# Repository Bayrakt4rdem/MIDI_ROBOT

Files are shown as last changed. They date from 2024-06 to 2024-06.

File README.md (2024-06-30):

# MIDI ROBOT

###### *Built for:*
- METU ME Department ME462 Capstone Project
###### *Built by:*
- Ege Sarp Dengizmen
- Erdem Bayraktar
- Muhammed Ömer Yiğit
- Omar Habib
- Seçkin Eren Yetim

<p align="center">

</p>

## Showcase Video
MIDI ROBOT SHOWCASE (https://www.youtube.com/watch?v=wqPkPyw_Kpk)

## Motivation of the Project

### What is MIDI Robot?
MIDI is a robotic project that focuses on improvised programmability and easy integration of additional sensors. It is made to be long-lasting and versatile with a design that conveniences assembly and manufacturing processes.

Its modular design is key to its ease of integration of new sensors and tools as mission needs change. This flexibility increases the robot's capacity to carry out a wide range of scientific studies for indoor environments with uninterruptable power supply.

Essential component of MIDI is its programmability, which gives researchers the ability to alter and improve robotic operations in real time with built in sensors and expandability. With comprehensive array of sensors and convenience to control them, it can be utilized by wide range of users that includes anyone from a beginner to a PhD student.

### Why is MIDI Robot Necessary?
Understanding the basic of robotics requires wide range of information from diverse professions combined. In fact, learning all discreate subject is exhausting and discouraging. MIDI robot is specifically designed to programming in ease by user. Furthermore, building and assembling this robot may teach the user diverse information about power electronics, mechanics and programming that includes pi pico and python with considerably less effort.

For expert users, MIDI may be considered as a strong candidate for testing their algorithms, making scientific researches or just for fun. With the expandable sensor design with proper communication between them, one can implement diverse tasks to MIDI without any worries about power-loss issues or lose data.

### Motivation Behind the Project
Learning the theoretical part of the robotic is always enjoyable for us. Still, without proper application, this knowledge is likely to be forgotten or become meaningless. For this project, we have aimed to apply our theoretical skills to build a robot that makes us feel satisfied. Still, building the robot was challenging. We learned lots of things while solving the problems that we faced. In fact, one can say that theory feeds the application but applicational issues creates the theory.

The main idea behind building the MIDI is helping the people to make their own robots to learn more about robotics and testing their codes and theoretical implementations. All the code implementations and mechanical designs are specifically made for learning the robotics in more convenient way. In fact, From high-school student to graduate students, anyone that really interested in robotics can use this robot to make some additions, to make some experiments or daily use that includes lots of fun.

### Acknowledgement and Credits

While doing this robot, we have faced diverse problems that is about the facility problems and guiding.   
We would like to thank the Ahmet Buğra Koku for guiding us, ROMER and METU Micromanufacturing Laboratory for allowing us to use their manufacturing infrastructure and resources.

## Main features

Structrually MIDI is expected to carry 15 kilograms without facing any problems. It is specifically designed for indoor use. Still, one can change some of the mechanical components of the MIDI to adapt MIDI for outdoor use.

With its modular design, one can add different sensors and payloads to the platform. Due to its modular design, it is very easy to add extra floors to the MIDI.

There are 4 bumpers on the corners of the robot to sense the collision of MIDI. These bumpers both act as a sensor and a mechanical spring.

4 ultrasonic sensors are implemented to sense the distance of the robot with respect to outer obstacles. This sensors can be used to prevent crashes and fall downs. 

A lidar, a wide-angle camera and an IMU is also implemented to perceive the environment in an enhanced manner to achieve diverse tasks.

As a power source an 18V Makita battery is used. There is also an extra UPS module on the robot, in order to prevent direct power cuts of the Raspberry Pi. 

## Shared Documentation and Files

  1. Bill of materials to make replication of the device easier
  2. PCB circuitry design and electronic schematic files   
  1. CAD design files to make further development available   
  1. STL design files for 3D printing availability
  1. Assembly manual for an easier assembly
  2. Software explanations and guides
  3. Example use cases

## Bill of Materials

### Off-the-shelf Materials Which Must be Purchased

To build the model that provided, one will need diverse sensors and components. One can found the necessary materials with some sample links below. 

#### Electronic components
- [MPU6050 IMU x 1](https://www.robotistan.com/mpu6050-6-eksen-ivme-ve-gyro-sensoru-6-dof-3-axis-accelerometer-and-gyros)
- [YL99 Impact Switch Module x 4](https://www.robolinkmarket.com/yl-99-darbe-svic-sensor-modulu)  
- [HC-SR04 Ultrasonic Distance Sensor x 4](https://www.robotistan.com/hc-sr04-ultrasonic-distance-sensor)
- [A4988 Stepper Motor Driver x2](https://www.robotistan.com/a4988-step-motor-surucu-karti-kirmizi)
- [YDLidar G2 x1](https://www.robotistan.com/ydlidar-g2-lidar-mesafe-sensoru)
- [NEMA17 Stepper Motor x 2](https://www.robolinkmarket.com/17hs4401-nema17-step-motor) 
- [Makita 18V Battery x1](https://www.powertoolworld.co.uk/brands/makita/makita-batteries-chargers/makita-batteries-18v-lxt)
- [UPS Module 3S x 1](https://www.amazon.com.tr/waveshare-Kesintisiz-UPS-Destekler-3S/dp/B0BQC2WNR8)
- [Rasberry Pi Pico x 1](https://www.robotistan.com/raspberry-pi-pico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)
- [Rasbeery Pi 4 x 1](https://www.robotistan.com/raspberry-pi-4-4gb)
- [lm2096 Voltage Regulator x 2](https://www.robotistan.com/mini-ayarlanabilir-3a-voltaj-regulator-karti-lm2596-adj) 
- [XL4016E1 DC-DC Step Down x 1](https://www.az-delivery.de/en/products/xl4016e-yh11060d)
- [Megapixel Wide Angle Fish Eye Camera x 1](https://www.amazon.com/Hilitand-Fisheye-Professional-Adjustable-Raspberry/dp/B0877439FF)
- [30x30 Fan x 1](https://www.rhino3dprinter.com/urun/30x30-fan-12v-ve-24v-secenekleriyle)
- [8 Strip Led x 2](https://www.robolinkmarket.com/neopixel-8li-serit)
- [100 μf Capacitor x 1 ](https://www.robotistan.com/25v-100uf-capacitor)
- [10 μf Capacitor x 2 ](https://www.robotistan.com/10-uf-16-v-elektrolit-kondansator)
- [20 pieces Neopixel Led strip x1](https://market.samm.com/adafruit-neopixel-dijital-rgb-led-serit-siyah-60-led-1m)

  Note that other NEMA17 models or other power supply models may be selected. Still, battery must be adjusted as 18 Volts.

#### Structural components

- [20x20 Sigma Profile 30cm x4](https://www.robolinkmarket.com/20x20-v-slot-sigma-profil-kanal-6-320mm)   
- [20x20 Sigma Profile 21cm x4](https://www.robolinkmarket.com/20x20-v-slot-sigma-profil-kanal-6-320mm)   
- [20x20 Sigma Profile 15cm x4](https://www.robolinkmarket.com/20x20-v-slot-sigma-profil-kanal-6-320mm)   
- [Sigma Connection Component x 12](https://www.robolinkmarket.com/20x20-genis-kose-baglanti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)   
- [M3 16mm Screw x 30](https://www.amazon.com/Phillips-Countersunk-Machine-Screws-100pcs/dp/B018RSUVFU)   
- [M4 16mm Screw x 30](https://www.amazon.com/Phillips-Machine-Screws-Metric-Thread/dp/B01HF7BLIA)   
- [M3 Nuts x 30](https://www.robotistan.com/m3-somun-50-adet)   
- [M4 Nuts x 30](https://www.robotistan.com/m4-somun)
- Bearings in specified dimensions in assembly step file.

  Note that sigma profiles are sold as whole 4-6 meters. Buying one and cutting in proper dimensions is necessary.

### Printed Parts
To make the MIDI robot more accessible and easy to replicate, most of the parts are suitable for 3D printing.    
The production files can be found under the /CAD_files directory.   
The STEP files are for further development and editing the model in any CAD environment. <br>
The STL files are for manufacturing the necessary parts with a 3D printer. <br>
 <br>
 
Note that soldering equipment will also be needed.
Below is the list of all the printed parts: 

1. Led casing part 1 x2 // CAD file name: Led_casing_part1
1. Led casing part 2 x2 // CAD file name: Led_casing_part2
1. Makita holder x1 // CAD file name: Makita_holder
1. Raspbery Pi holder bottom part x1 // CAD file name: Rasp_pi_holder_bottom
1. Raspberry Pi holder top part x1 // CAD file name: Rasp_pi_holder_top
1. UPS holder x1 // CAD file name: UPSholder
1. Ultrasonic sensor holders x4 // CAD file name: Ultrasonic_holder
1. Bumper x4 // CAD file name: bumper
1. Button box x1 // CAD file name: button_holder
1. Camera holder x1 // CAD file name: camera_holder
1. Rim caster tire x4 // CAD file name: castertire_rim_v1
1. Alternative for caster tire x4 // CAD file name: castertire_v1
1. Alternative for caster tire x4 // CAD file name: castertire_v2
1. Alternative for caster tire x4 // CAD file name: castertire_v3
1. Alternative for caster tire x4 // CAD file name: castertire_v4
1. Alternative for caster tire x4 // CAD file name: castertire_v5
1. Main PCB holder x1 // CAD file name: mainPCBholder
1. Main tire alternative rim x2 // CAD file name: maintire_rim_v1
1. Main tire alternative rim x2 // CAD file name: maintire_rim_v2
1. Main tire alternative x2 // CAD file name: maintire_v1
1. Main tire alternative x2 // CAD file name: maintire_v2
1. Sigma sensor and modular holder connection x16 // CAD file name: modular_sigma_connections
1. Plexy holders x8 // CAD file name: plexy_holder
1. Power PCB  holder x1 // CAD file name: powerPCBholder
1. Sigma corner connection x8 // CAD file name: sigma_corner_connection
1. Alternative sigma corner connection x8// CAD file name: sigma_corner_connection_previous
1. Spring version 1 x4 // CAD file name: spring_v1
1. Spring version 2 x4 // CAD file name: spring_v2
1. Wheel holder part x3 // CAD file name: tire_holder
1. Side wheel gear 1 // CAD file name: wheel_holder_gear1
1. Side wheel gear 2 // CAD file name: wheel_holder_gear2
1. Side wheel carrying assembly part 1 x2 // CAD file name: Wheel_holder_part1
1. Side wheel carrying assembly part 2 x2 // CAD file name: wheel_holder_part2
1. Back wheel carrying assembly x1 // CAD file name: Back_wheel_holder
1. Caster tire holder x4 // CAD file name: Caster_tire_connectors

## Printing Settings for 3D Printed Parts

There are 2 main materials and settings used for 3D printed parts.   
For the elastic components such as springs and tires, TPU material is used.   
For the remaining parts, PLA material is used.   

[Link for the TPU filament](https://www.porima3d.com/porima-tpu-flex-esnek-95a-filament-175mm-1kg)   
[Link for the PLA filament](https://www.porima3d.com/porima-pla-filament-175mm-1kg)     

The production files can be found under the /CAD_files directory.   
The STEP files are for further development and editing the model in any CAD environment. <br>
The STL files are for manufacturing the necessary parts with a 3D printer. <br>
 <br>
 
The recommended settings for slicing the STL files for PLA material are as follows: <br>
3D Printer Model: Creality CR-6 SE 
Material: PLA filament <br>
Nozzle / build plate temperature: 210 / 65 degrees <br>
Layer height: 0.2 mm <br>
Initial layer height: 0.2 mm <br>
Line width: 0.4 mm <br>
Wall line count: 3 <br>
Infill density: 30.0% <br>
Infill pattern: Lines <br>
Print speed: 70.0 mm/s <br>
Infill speed: 100.0 mm/s <br>
Wall speed: 35.0 mm/s <br>
Initial layer speed: 35.0 mm/s <br>
Fan: ON <br>
Supports: ON / Normal 45 degree overhang <br>
Adhesion type: NO <br>

The recommended settings for slicing the STL files for TPU material are as follows: <br>
3D Printer Model: Ender 3 V2 (modified for direct drive extrusion)
Material: TPU filament <br>
Nozzle / build plate temperature: 215 / 65 degrees <br>
Layer height: 0.2 mm <br>
Initial layer height: 0.2 mm <br>
Line width: 0.8 mm <br>
Wall line count: 3 <br>
Infill density: 100.0% <br>
Infill pattern: Lines <br>
Print speed: 50.0 mm/s <br>
Infill speed: 50.0 mm/s <br>
Wall speed: 25.0 mm/s <br>
Initial layer speed: 35.0 mm/s <br>
Fan: ON <br>
Supports: OFF / Normal 45 degree overhang <br>
Adhesion type: NO <br>

## Power Circuitry

Basically in our power circuitry we have 18V, 12.8V, 5V, 3.3V power lines.

- 18 Volts Power is used to feed UPS and the UPS feeds the Raspberry Pi
- 18 Volts power is transformed into 12 Volts to feed the steppers
- 12 Volts power is transformed into 5 Volts to feed the led strips
- 12 Volts Power is also transformed into 3.3 Volts to feed the Raspberry Pi Pico and rest of the sensors.

### Electronic Diagrams & PCB Designs

The PCB Files and Electronic Schematics can be found under the PCB&Schematics/ directory.  
The Fusion 360 software is used while designing the PCB circuit. <br>

The PCB is designed as single layer, in order to make fabrication process easier. <br>
But due to size limitations of the PCB, not all the wiring fit into one layer. <br>
As a result there is two options: <br>
Easier option: Fabricate only the top layer as a single layer PCB and make additional air wiring afterwards.<br>
(less than 10 additional airwires are  necessary). <br>
Second option: Fabricate the PCB as a two layer one. <br>

### Assembly Guideline

1. Cut the sigma aluminum profiles in given lenghts.
1. Insert the sigma modular holders into specific positions on sigma slots, as you wish.
1. Insert the led casings into the two sides of the sigmas.
1. Connect the sigma aluminums using sigma corner connections and obtain a rectangular sigma box.
1. Assemble the side wheel holder assembly, insert gearbox inside and mount the stepper motors.
1. Connect the side wheel assembly to the main sigma body using wheel holder part.
1. Connect the back wheel carrying assembly to the main sigma body using wheel holder part.
1. Insert the caster tire holders and connect the caster tires into them.
1. Connect the main wheels.
1. Insert the springs on above wheels.
1. Mount the plexy plates on both floors.
1. Insert sensors and components using their own casings and holders.
1. Make the necessary cablings and check the circuit using a multimeter.
1. Now you can power up your robot and start HAVING FUN!

## Software Documentation

### Software and Versions
### Installing Guide
This project uses a Raspberry Pi 4b as the main computer of the robot. Flash the latest Raspberry Pi OS 64-bit version onto your sd card. We recommend using the **PiImager**. Make sure to configure your image to your needs (enable SSH, set wlan key and password, setup username and password). Flash the sd card, insert it into your Pi and power it on. Now, to **SSH** into RPi4, open up a terminal on the PC and use the command `ssh pi@<yourusername>.local`. The console will ask for your password, enter it. In order to setup the Pi, you should clone the software files repo into your home adress using `git clone`, after the files are cloned go inside the `Raspi_files`. Inside the `Raspi_Files` folder give execution rights to the setup file using, `chmod +x setup_pi.bash` and then relax :) the script will take care of all the Pi configuration, docker installation, building of the docker container, adding necessesary configs modifications etc. Feel free to inspect the bash script. <br>
**Important Note:** this script adds a function to your `.bashrc` such that everytime you ssh into your Pi the project docker container opens up. You can modify your `.bashrc` file to change this behaviour as needed.  <br>
After the script the Pi will reset itself, you can just go inside `Examples` and try some examples. Provided that you pip installed the projects python package. See below for that. <br>
### Why Use Docker?
We have opted with using a Docker image because it allows for end-users like you to get right into the action with a ready to use image with all required dependencies of our project pre built into it. One more advantage of this is even if you are not running on a RPi 4 you can still use the Dockerfile provided in **Docker_files** folder to build the ready to use image and get started on whatever software you are running. If you want to add functionality just modify the docker file and rebuild it again.
<br>

### Rasberry Pi Pico/ESP
MIDI has Raspberry Pi Pico W microcontroller. MIDI can be used with any microcontroller(ESP32) that can be coded in MicroPython. <br>
To flash MicroPython into Pico W, this [tutorial](https://projects.raspberrypi.org/en/projects/getting-started-with-the-pico/3) could be followed. After flashing MicroPython, the provided scripts should be uploded into Pico W from [here](https://github.com/momeryigit/ME462-MIDI/tree/omar-test/sarp-esp).

#### Pico Side Command Handler

This document explains the different commands handled by the `command_handler` function on the Pico microcontroller. Each command is parsed and executed to control various components like stepper motors, Neopixel LEDs, and other functionalities.

##### Command Format

Commands are received as a list (`msg`) where:
- `msg[0]`: Command identifier (e.g., `"s"`, `"t"`, `"np"`, `"h"`, `"PAUSE"`, `"CONTINUE"`, `"EMERGENCY_STOP"`, `"re-config"`).

#### Supported Commands:

##### Stepper Motor Commands

1. **Drive Stepper at a Frequency**
    - Command: `"s l 500"`
    - Description: Drives the specified stepper at a given frequency.
    - `msg[1]`: Stepper identifier (`"l"` for left, `"r"` for right).
    - `msg[2]`: Frequency in Hz.
    - Example: `"s l 500"` drives the left stepper at 500 Hz.

2. **Drive Stepper for a Number of Ticks in a Duration**
    - Command: `"t r 100 5"`
    - Description: Drives the specified stepper for a certain number of ticks within a given duration.
    - `msg[1]`: Stepper identifier (`"l"` for left, `"r"` for right).
    - `msg[2]`: Number of ticks.
    - `msg[3]`: Duration in seconds.
    - Example: `"t r 100 5"` drives the right stepper 100 ticks in 5 seconds.

###### Neopixel LED Commands

1. **Turn Off All Neopixels**
    - Command: `"np off"`
    - Description: Turns off all Neopixel LEDs.

2. **Fill All Neopixels with a Color**
    - Command: `"np fill 100 0 0"`
    - Description: Fills all Neopixels with the specified RGB color.
    - `msg[2]`: Red value (0-255).
    - `msg[3]`: Green value (0-255).
    - `msg[4]`: Blue value (0-255).
    - Example: `"np fill 100 0 0"` sets all Neopixels to red.

3. **Set Specific Neopixel Color**
    - Command: `"np set 1 4 0 55 0"`
    - Description: Sets a specific Neopixel's color.
    - `msg[2]`: Neopixel strip ID.
    - `msg[3]`: Pixel index in the strip.
    - `msg[4]`: Red value (0-255).
    - `msg[5]`: Green value (0-255).
    - `msg[6]`: Blue value (0-255).
    - Example: `"np set 1 4 0 55 0"` sets the 4th pixel of strip 1 to green.

###### Control Commands

1. **Heartbeat Response**
    - Command: `"h"`
    - Description: Resets the watchdog timer to keep the system alive.

2. **Pause Operation**
    - Command: `"PAUSE"`
    - Description: Pauses all operations until the `CONTINUE` command is received.

3. **Continue Operation**
    - Command: `"CONTINUE"`
    - Description: Resumes operations after a `PAUSE`.

4. **Emergency Stop**
    - Command: `"EMERGENCY_STOP"`
    - Description: Immediately stops all stepper motors and sets Neopixels to a warning color.

5. **Re-configure Robot**
    - Command: `"re-config"`
    - Description: Re-initializes the robot, waiting for a handshake and a new configuration file.
    - Note: Must send the `PAUSE` command before re-configuring.

##### Usage Example

Here is an example of how the `command_handler` might be used in a script:

```python
# Example usage of command_handler
msg = ["s", "l", "500"]

msg = ["np", "fill", "100", "0", "0"]

msg = ["PAUSE"]

msg = ["CONTINUE"]
```

##### Function Parameters

- `comm`: An instance of the `SerialComm` class for communication.
- `msg`: List containing the parsed command message.
- `hb`: An instance of the `Heartbeat` class.
- `steppers`: An instance of the `Steppers` class.
- `sensors`: An instance of the `Sensors` class.
- `neopixels`: An instance of the `NeoPixelStrips` class.

### Notes

- Ensure the `PAUSE` command is sent before the `re-config` command to safely re-initialize the robot.
- The `GET_STATUS` commands is a placeholder and will be implemented soon.
- Test the pico commands directly, for example, by using [Thonny](https://thonny.org/).

### API
Midibot's API is open-source and published on PYPI (see the latest version [here](https://pypi.org/project/romer-midibot/)). It requires Python 3.6 or newer and `pyserial`.

To install `pyserial`, you can use:
```bash
pip install pyserial
```

To install `romer-midibot`, you can use:
```bash
pip install romer-midibot
```

This API is designed to connect to, control, and get readings from Midibot using Python. First, import the `DifferentialDriveRobot` class:
```python
from romer_midibot import DifferentialDriveRobot as Robot
```

To initialize a robot class:
```python
robot = Robot(serial_port="replace_with_your_serial_port")
```

#### The arguments are as follows:
- **`serial_port` (str)**: Serial port on PC or Raspberry Pi for connecting to the robot.
- **`baudrate` (int, optional)**: Baud rate for serial communication. Defaults to 115200.
- **`timeout` (int, optional)**: Timeout in seconds for communication operations. Defaults to 1.
- **`ip` (str, optional)**: IP address of Pico for socket communication. Defaults to "192.168.137.28".
- **`config_file` (str, optional)**: Path to the config.json file. Defaults to None.
- **`socket_port` (int, optional)**: Port for socket communication on PC or Raspberry Pi. Defaults to 8080.
- **`stepper_ids` ([int], optional)**: Integer array of stepper motor IDs. Defaults to [1, 2].
- **`u_ids` ([int], optional)**: Integer array of ultrasonic sensors. Defaults to [1, 2, 3, 4].
- **`b_ids` ([int], optional)**: Integer array of bumper sensors. Defaults to [1, 2, 3, 4].
- **`imu_connected` (bool, optional)**: Whether IMU is connected. Defaults to False.
- **`u_median_filter_len` (int, optional)**: Length of median filter window. Defaults to 3.
- **`default_emergency_behavior` (bool, optional)**: Default behavior of bumper switches coded on Pico. Defaults to True. Change to False if custom behavior is desired. Bumper switches will be polled for data if enabled.

To initialize the robot API, there are two methods:
1. Manually enter parameters into the class initializer.
2. Use a config file.

* **1**: To initialize by manually entering parameters, keep `config_file` as `None` and modify the other default parameters as desired. The API enables/disables robot peripherals as defined by initialized parameters from the user, which will be merged with a default [config_file](https://github.com/momeryigit/ME462-MIDI/blob/main/romer_midibot/romer_midibot/default_configs.py) to send to the Pi Pico.

* **2**: To use a config file, ignore the other parameters, and provide the path to your `config_file.json`. It should be similar to [this](https://github.com/momeryigit/ME462-MIDI/blob/main/romer_midibot/romer_midibot/default_config.json). Example:
```python
robot = Robot(serial_port="COM6", config_file=r"path/to/your/config/file")
```

Once your robot is initialized, you can connect via serial or socket (still in development) as follows:
```python
robot.connect(connection_type="serial")
```
```python
robot.connect(connection_type="socket")
```
Given that the Pi Pico is running and waiting for a connection, handshakes will be exchanged, and the config file will be sent to the Pico where it will initialize from it. If all this is successful, you are ready to send commands to the robot and receive data from it. The API will start a thread just to poll serial or socket ports and manage received data.

#### Robot Commands
* To set a data callback function that will be called whenever data is received:
```python
robot.set_data_callback(callback)
```
  - **`callback`**: Callback function called with raw data, whenever received from serial. Keep it low cost to prevent lag in data polling.

* To manually send a command to the robot:
```python
robot.send_command(command)
```
  - **`command`**: Command string sent to Pico.

* To send a pause command:
```python
robot.send_pause_command()
```
This stops all the robot's movements and data sending until either a continue or re-config command is received.

* To send a continue command:
```python
robot.send_continue_command()
```

* To disconnect from the robot:
```python
robot.disconnect()
```

* To configure the Pico with the sensor and motor configuration:
```python
robot.pico_config()
```

* To reconfigure the Pico with a new configuration file:
```python
robot.pico_reconfig(config_file)
```
  - **`config_file`**: Path to the new configuration file.

* To set the number of ticks and duration for the left and right wheels of the robot:
```python
robot.set_ticks_duration(left_ticks, right_ticks, duration_l, duration_r)
```
  - **`left_ticks`**: Number of ticks for the left wheel.
  - **`right_ticks`**: Number of ticks for the right wheel.
  - **`duration_l`**: Duration for the left wheel to complete the ticks. In s
  - **`duration_r`**: Duration for the right wheel to complete the ticks. In m

* To set the distance for each wheel and the duration to reach the distance:
```python
robot.set_distance_duration(left_distance, right_distance, duration_l, duration_r)
```
  - **`left_distance`**: Distance for the left wheel. In m
  - **`right_distance`**: Distance for the right wheel. In m
  - **`duration_l`**: Duration for the left wheel to reach the distance. In s
  - **`duration_r`**: Duration for the right wheel to reach the distance. In s

* To set the speed of the left and right wheels of the robot:
```python
robot.set_speed(left_speed, right_speed)
```
  - **`left_speed`**: Speed, in frequency, of the left wheel.
  - **`right_speed`**: Speed, in frequency, of the right wheel.

* To move the robot forward for a specified duration:
```python
robot.move_forward(duration=1, speed=500)
```
  - **`duration`**: Duration, in seconds, to move forward. 
  - **`speed`**: Speed, frequency, at which to move forward.

* To rotate the robot at a given speed in a given direction for a set duration:
```python
robot.rotate(duration=5, speed=800, direction="cw")
```
  - **`duration`**: Duration to rotate. In seconds
  - **`speed`**: Speed at which to rotate. In frequency
  - **`direction`**: Direction to rotate ("cw" for clockwise, "ccw" for counterclockwise).

* To convert desired linear and angular speeds to wheel frequencies and set the robot speed:
```python
robot.send_twist(linear_speed, angular_speed)
```
  - **`linear_speed`**: Linear speed. In m/s
  - **`angular_speed`**: Angular speed. In rad/s

* To stop the robot:
```python
robot.stop()
```

* To immediately stop the robot:
```python
robot.emergency_stop()
```

* To turn off the LEDs on the robot:
```python
robot.turn_leds_off()
```

* To fill all LEDs with a given color:
```python
robot.fill_leds(color)
```
  - **`color`**: Color to fill the LEDs with. RGB tuple (100, 20, 20) for example

* To set the color of a single LED pixel:
```python
robot.set_led_pixel(np_id, pixel_index, color)
```
  - **`np_id`**: ID of the neopixel strip.
  - **`pixel_index`**: Index of the LED pixel.
  - **`color`**: Color to set the LED pixel. RGB tuple (100, 20, 20) for example

* To get sensor data from the robot (default is ultrasound sensor data):
```python
robot.get_sensor_data(sensor_type="u")
```
  - **`sensor_type`**: Type of sensor data to get ("u": ultrasonic, "b": bumper, "i", imu).

* To request the current status of the robot:
```python
robot.get_status()
```

* Destructor to stop the robot and disconnect on deletion:
```python
del robot
```

Be sure to send disconnect command before unplugging the pico. Refer to examples or demos for example uses of the API.

## Trying out the ROS nodes
Midibot comes with some essentials to get you starting on using ROS2 on midibot. The provided docker container is ROS2 ready, all you have to do is go inside the `dev_ws` folder and run `colcon build --symlink-install`. This will build the source files and ready up your systen for testing. After build is complete make sure to source the enviorement by using `source install/setup.bash` (.bash/.zsh depending on the terminal you are using). This command essentially includes our ROS2 packages in that current terminal session. The core ROS installation is sourced in every terminal since `source /opt/ros/iron/setup.bash` is included inside the .bashrc file of the docker image. The command simply overlays our package contents over the core ROS2 installation. <br>
After sourcing you can get into testing. Simply run the launch file for RPi using `ros2 launch midi_bringup pi.launch.py`, this runs the node for serial communication and the lidar if given as an argument `ros2 launch your_package pi.launch.py lidar:=true`. Then on your PC again source the ROS2 enviorement and run `ros2 launch midi_bringup drive.launch.py`. This sets up the PC side nodes, opens Rviz and sets up the controller nodes. Then by connecting an xbox controller to your machine you can control the robot using the controller. <br>

## Conclusion
The MIDI Robot is a versatile and accessible platform designed for both beginners and experts in robotics. Its modular design and easy programmability allow users to integrate new sensors and tools as needed, making it adaptable for various scientific and educational applications. With MIDI, users can gain hands-on experience in electronics, mechanics, and programming, bridging the gap between theory and practice. This robot is ideal for learning and experimenting, providing an approachable entry point for newcomers while offering advanced capabilities for seasoned researchers. Overall, the MIDI Robot empowers users to explore and innovate in robotics, making it a valuable tool for education, research, and personal projects. Its design ensures reliability and ease of use, fostering a deeper understanding and appreciation of robotic systems.

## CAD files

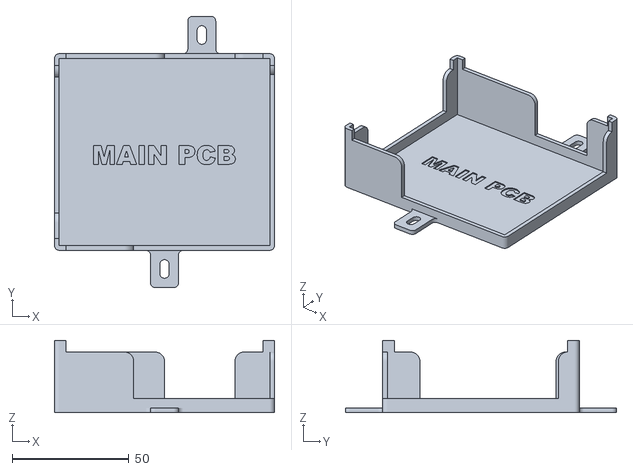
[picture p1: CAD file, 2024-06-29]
CAD_files/STL_files_to_3Dprint/mainPCBholder.stl
94.4 x 116.4 x 31.0

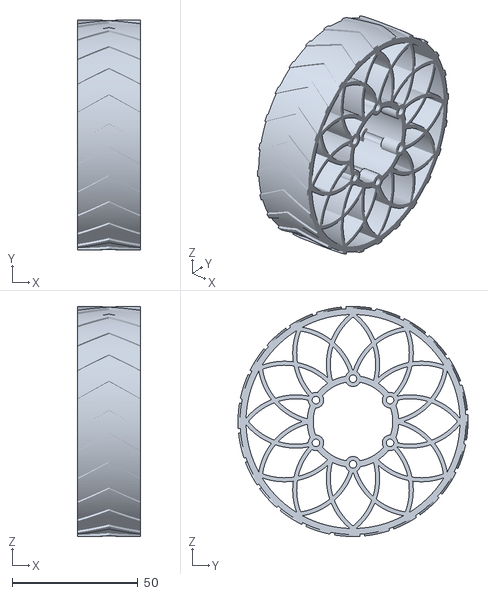
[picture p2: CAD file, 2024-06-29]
CAD_files/STL_files_to_3Dprint/maintire_v2.stl
25.0 x 91.4 x 91.4

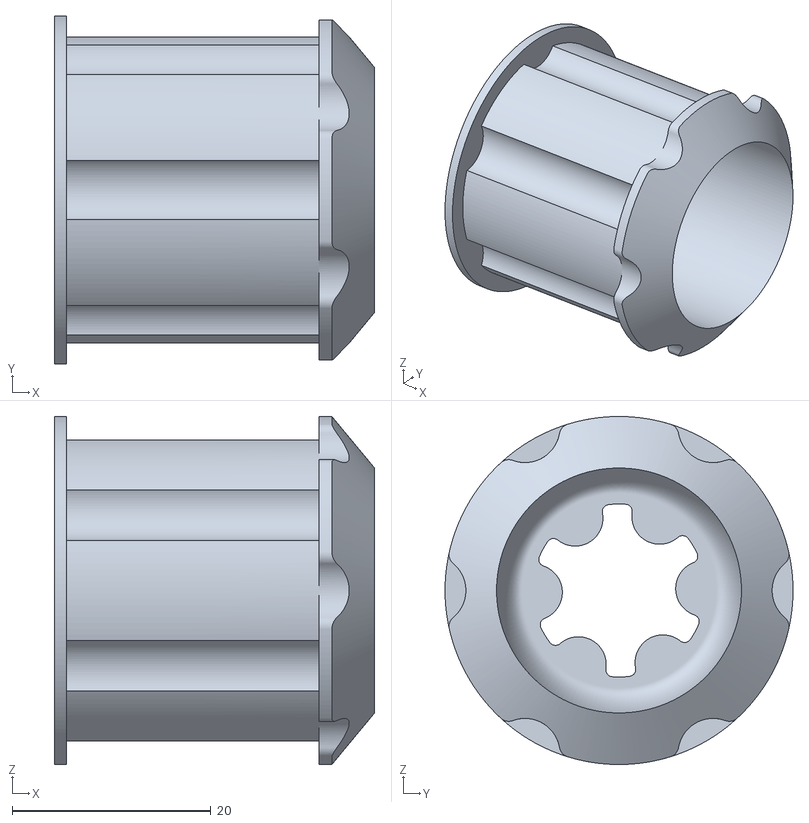
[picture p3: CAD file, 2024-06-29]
CAD_files/STL_files_to_3Dprint/maintire_rim_v2.stl
32.2 x 35.0 x 35.0

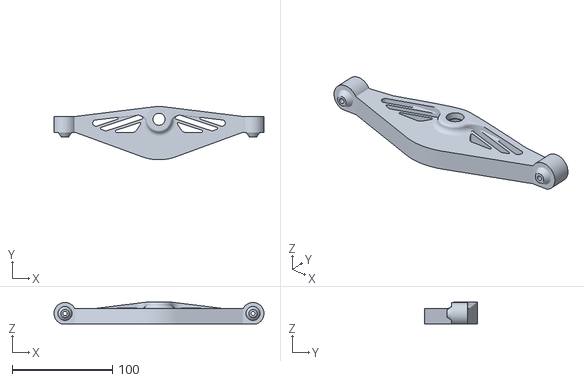
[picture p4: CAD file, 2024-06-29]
CAD_files/STL_files_to_3Dprint/Back_wheel_holder.stl
210.0 x 53.4 x 21.7

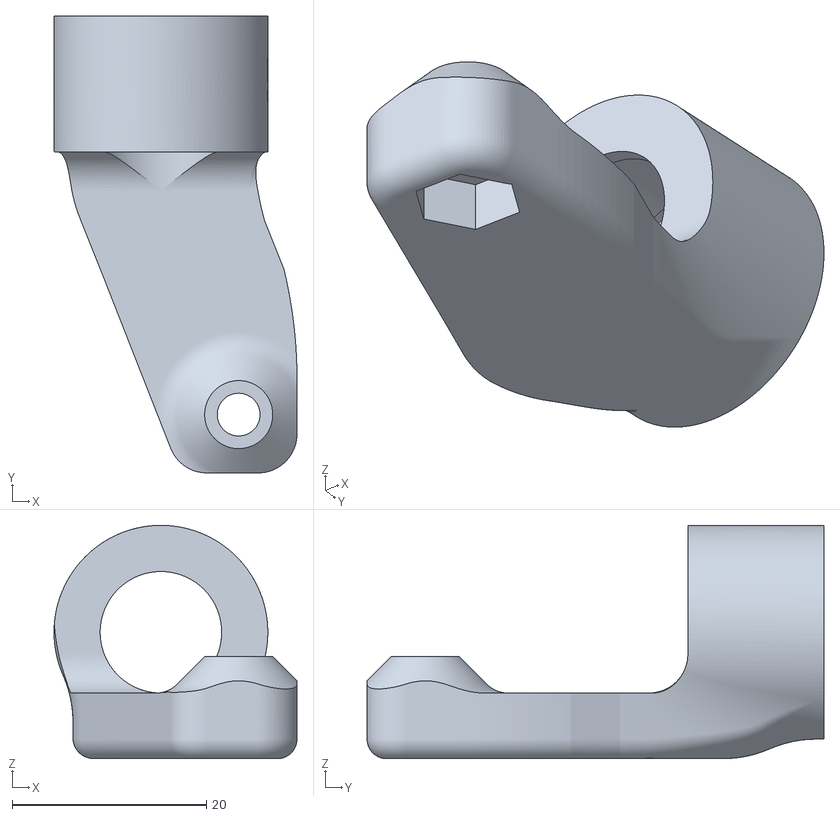
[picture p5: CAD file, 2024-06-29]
CAD_files/STL_files_to_3Dprint/Caster_tire_connectors.stl
25.0 x 47.0 x 24.0

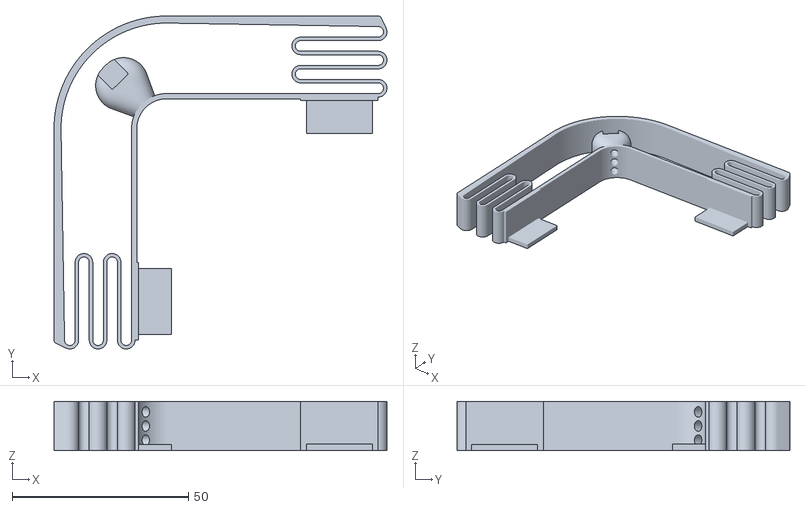
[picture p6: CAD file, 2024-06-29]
CAD_files/STL_files_to_3Dprint/bumper.stl
94.5 x 94.5 x 14.0

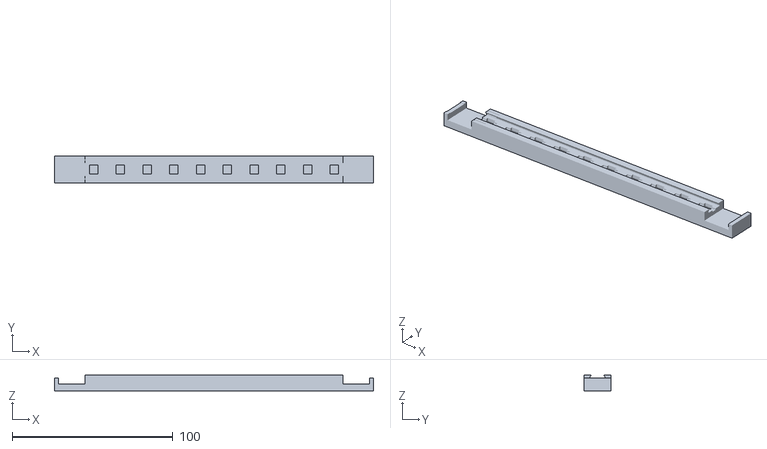
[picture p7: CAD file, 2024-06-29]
CAD_files/STL_files_to_3Dprint/Led_casing_part1.stl
198.7 x 16.7 x 9.66

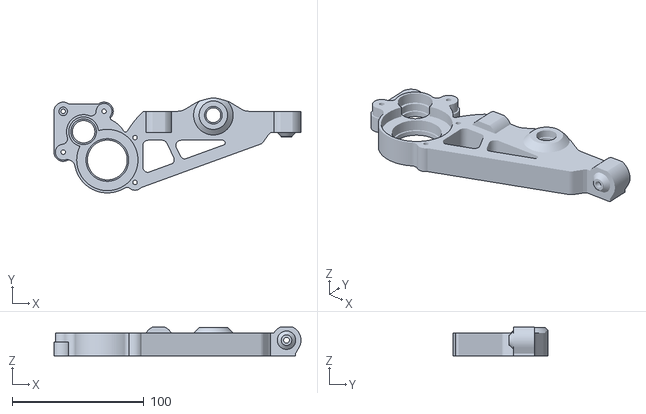
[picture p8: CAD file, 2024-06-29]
CAD_files/STL_files_to_3Dprint/Wheel_holder_part1.stl
187.5 x 72.0 x 22.0

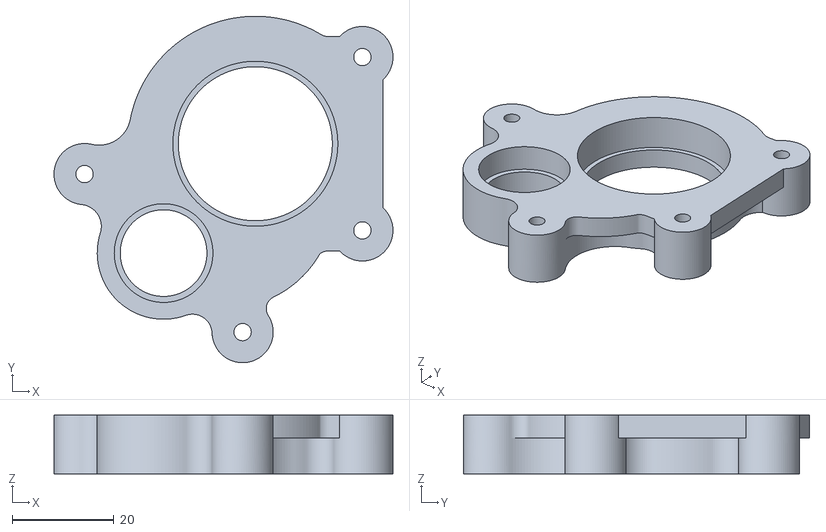
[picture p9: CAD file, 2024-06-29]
CAD_files/STL_files_to_3Dprint/wheel_holder_part2.stl
66.5 x 67.9 x 11.5

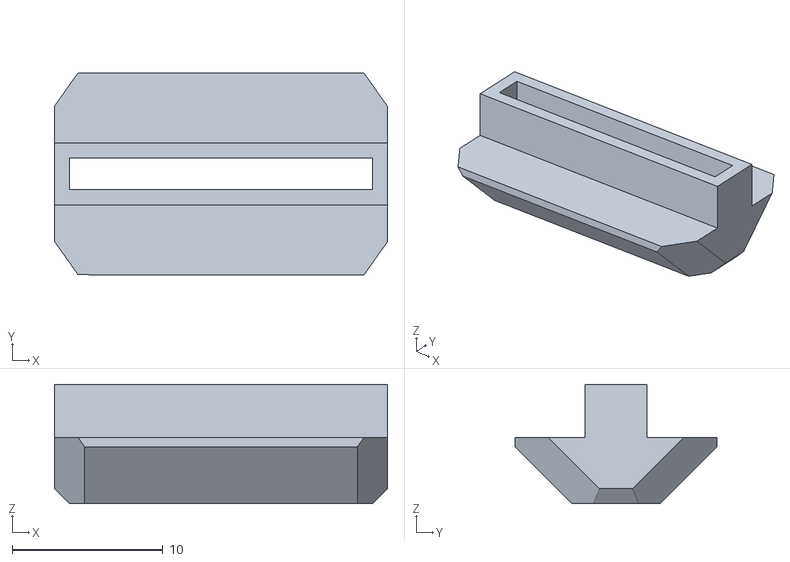
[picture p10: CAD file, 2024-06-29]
CAD_files/STL_files_to_3Dprint/modular_sigma_connections.stl
22.1 x 13.4 x 7.93

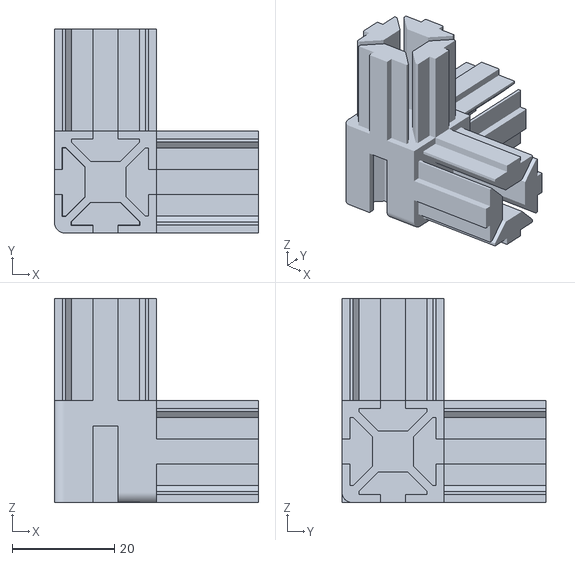
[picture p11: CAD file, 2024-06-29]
CAD_files/STL_files_to_3Dprint/sigma_corner_connection.stl
40.0 x 40.0 x 40.0

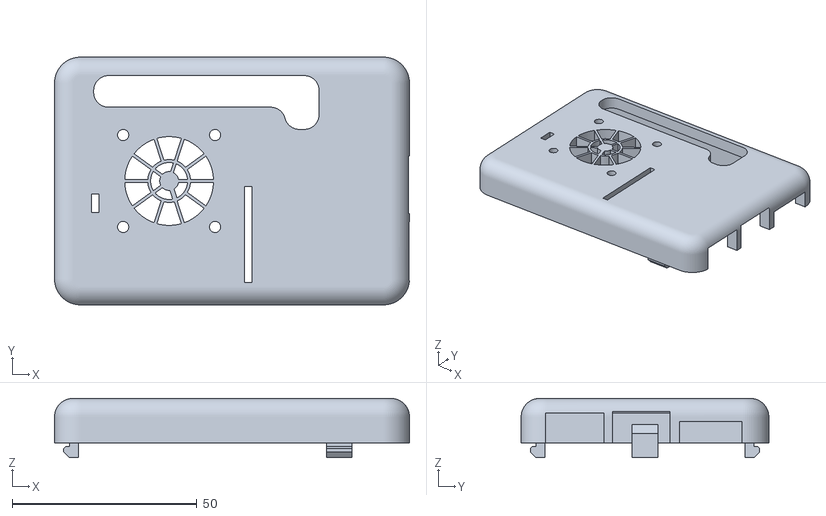
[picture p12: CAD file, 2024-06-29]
CAD_files/STL_files_to_3Dprint/Rasp_pi_holder_top.stl
96.0 x 67.0 x 16.0

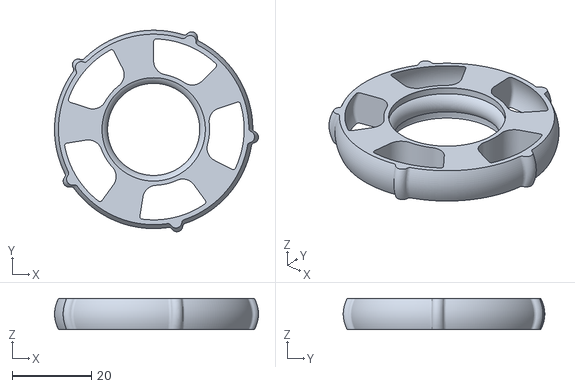
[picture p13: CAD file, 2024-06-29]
CAD_files/STL_files_to_3Dprint/castertire_v4.stl
51.4 x 50.8 x 7.82

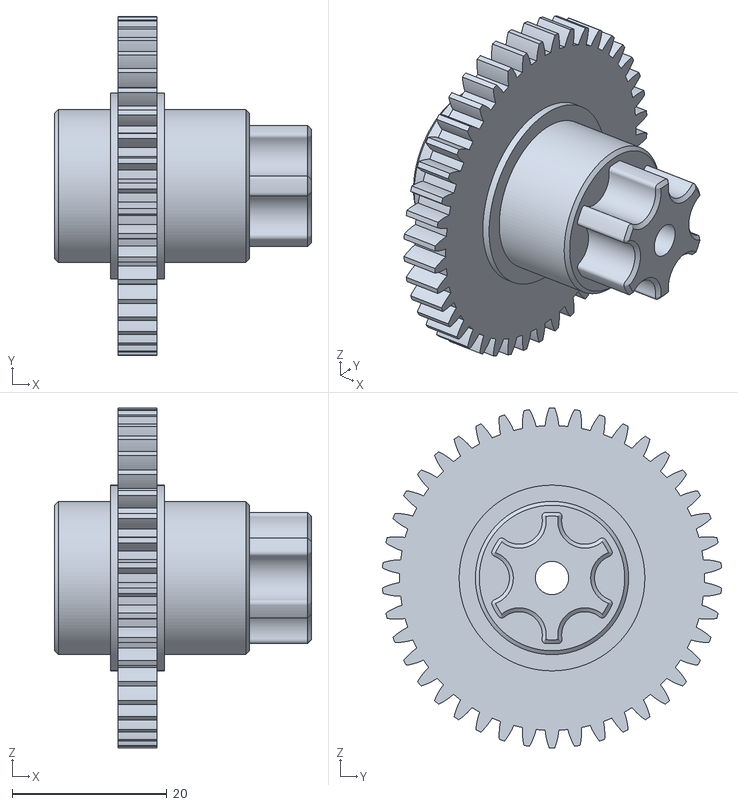
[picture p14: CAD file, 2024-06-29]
CAD_files/STL_files_to_3Dprint/wheel_holder_gear1.stl
33.3 x 43.8 x 43.9

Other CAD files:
CAD_files/STL_files_to_3Dprint/wheel_holder_gear2.stl
CAD_files/STL_files_to_3Dprint/tire_holder.stl
CAD_files/STL_files_to_3Dprint/plexy_holder.stl
CAD_files/STL_files_to_3Dprint/Ultrasonic_holder.stl
CAD_files/STL_files_to_3Dprint/Led_casing_part2.stl
CAD_files/STL_files_to_3Dprint/Makita_holder.stl
CAD_files/STL_files_to_3Dprint/Rasp_pi_holder_bottom.stl
CAD_files/STL_files_to_3Dprint/UPSholder.stl
CAD_files/STL_files_to_3Dprint/button_holder.stl
CAD_files/STL_files_to_3Dprint/camera_holder.stl
CAD_files/STL_files_to_3Dprint/castertire_rim_v1.stl
CAD_files/STL_files_to_3Dprint/castertire_v2.stl
CAD_files/STL_files_to_3Dprint/castertire_v3.stl
CAD_files/STL_files_to_3Dprint/maintire_rim_v1.stl
CAD_files/STL_files_to_3Dprint/maintire_v1.stl
CAD_files/STL_files_to_3Dprint/powerPCBholder.stl
CAD_files/STL_files_to_3Dprint/sigma_corner_connection_previous.stl
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

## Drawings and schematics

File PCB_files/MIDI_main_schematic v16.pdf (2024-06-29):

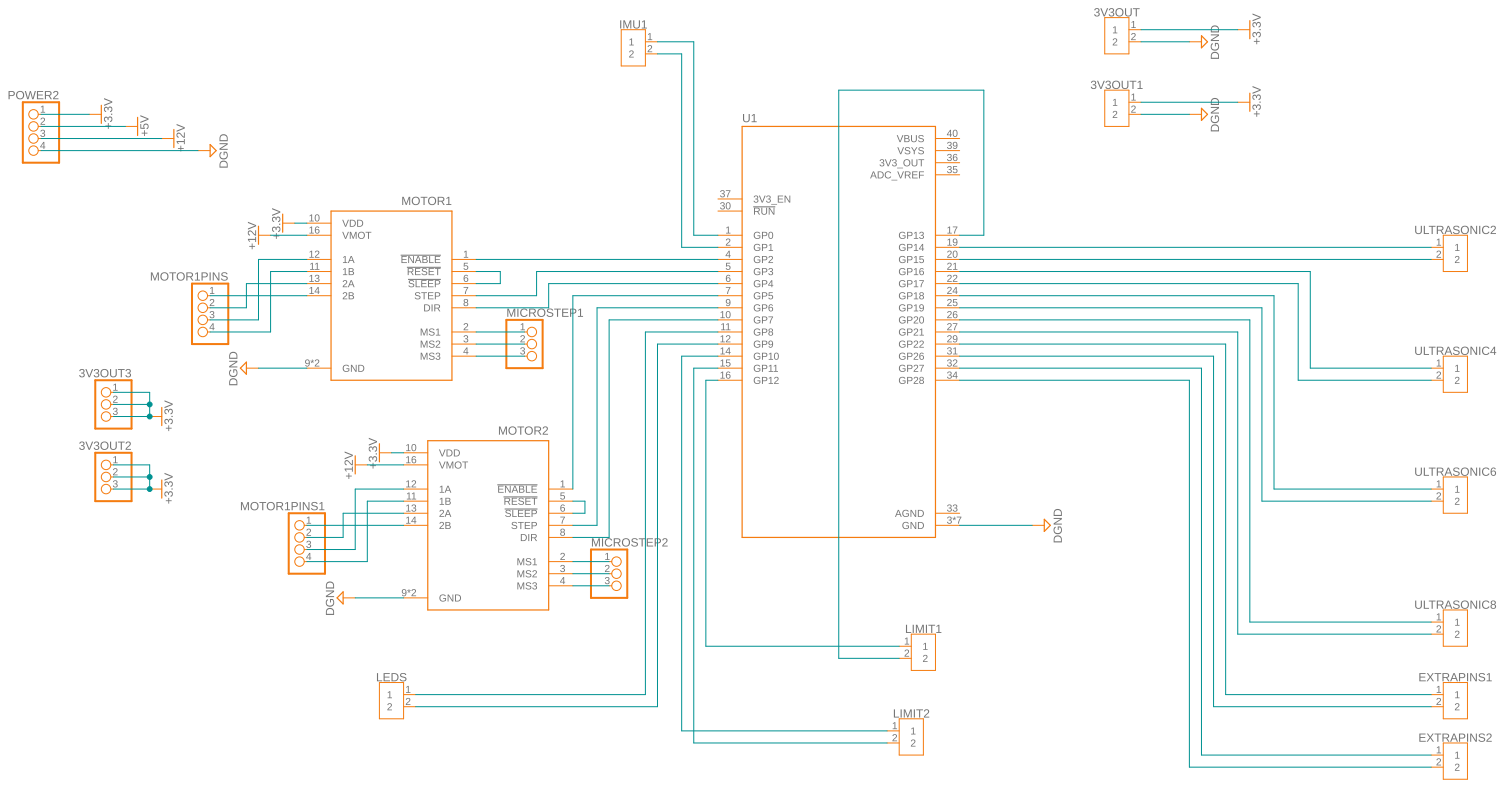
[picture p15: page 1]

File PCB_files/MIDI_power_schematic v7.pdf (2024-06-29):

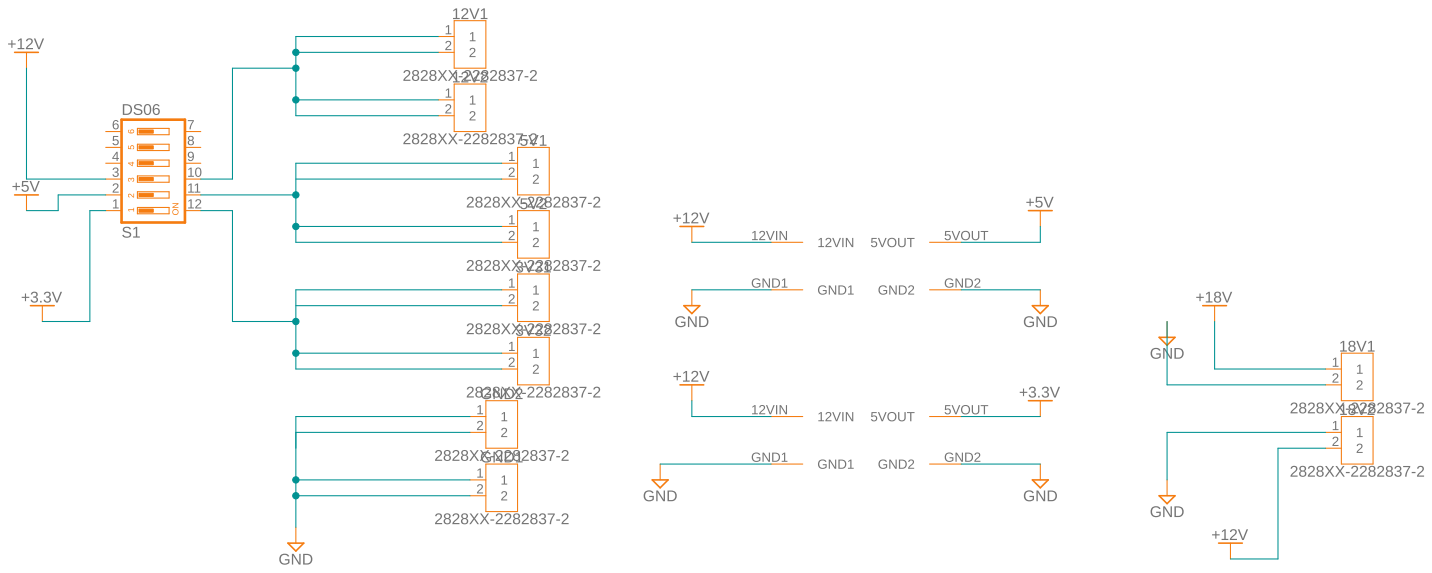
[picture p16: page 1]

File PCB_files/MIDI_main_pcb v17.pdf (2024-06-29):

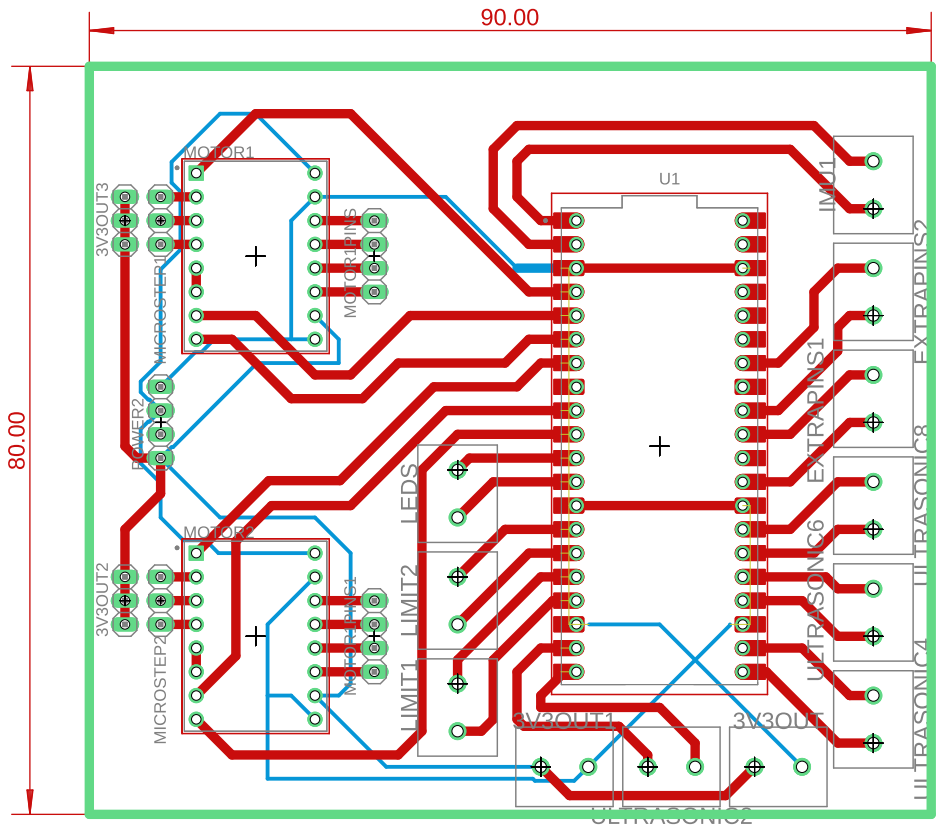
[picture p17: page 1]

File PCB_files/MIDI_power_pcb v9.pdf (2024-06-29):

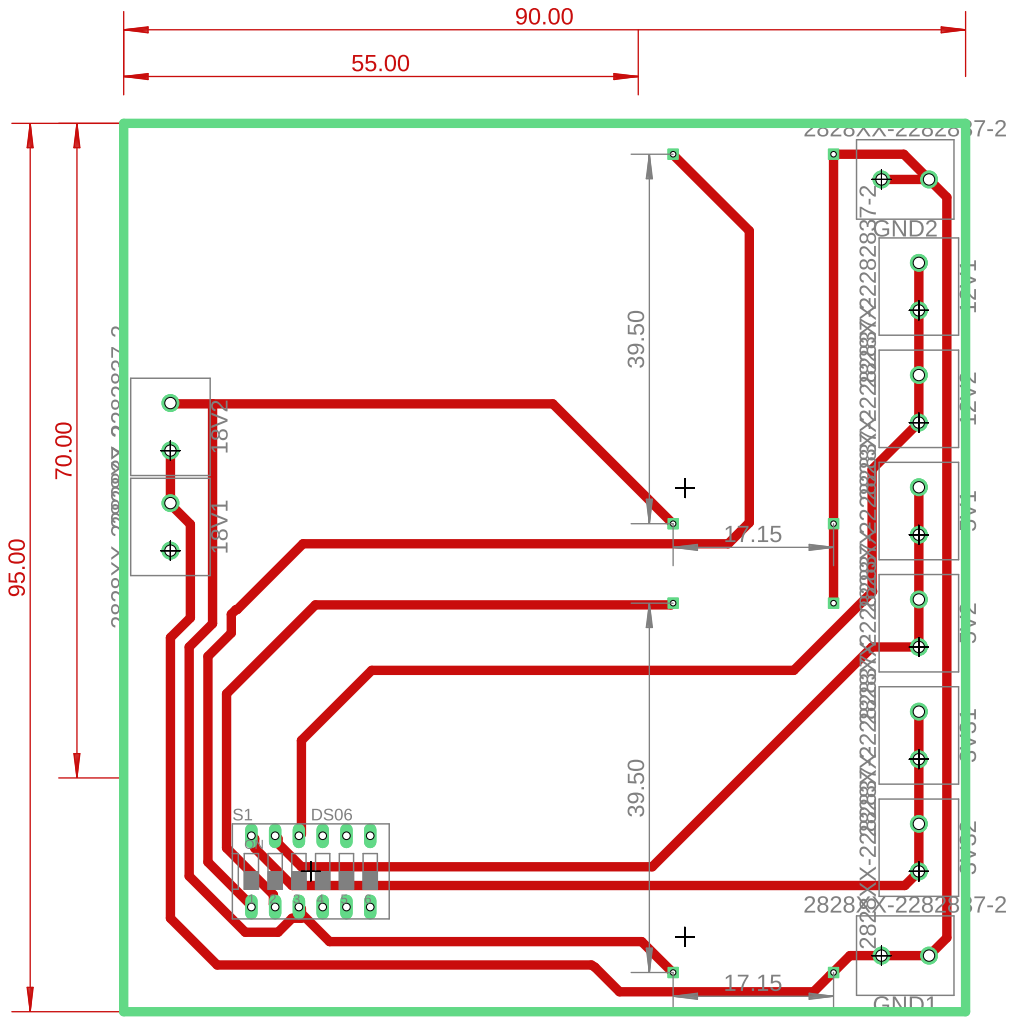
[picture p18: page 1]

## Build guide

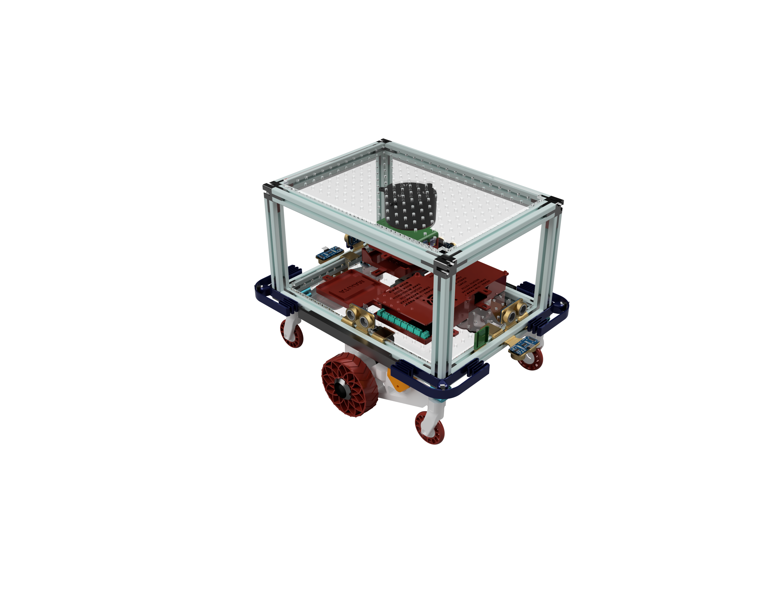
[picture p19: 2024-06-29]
Pictures/ASSEMBLY_EB_alternative_2024-Jun-29_01-01-18AM-000_CustomizedView5368189858_png_alpha.png

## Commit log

2024-06-29 Cad files added
    [Led_casing_part1.stl, Led_casing_part2.stl, Makita_holder.stl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]
2024-06-29 PCB production files added
    [Back_wheel_holder.stl, Caster_tire_connectors.stl]
2024-06-29 Added Pico Commands and command handler
